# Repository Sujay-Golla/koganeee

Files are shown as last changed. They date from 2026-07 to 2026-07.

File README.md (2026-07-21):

# Koganeee 
(JJK Reference) Flying room voice assistant with a screen  

## Inspiration
As a Jujutsu Kaisen fan and an admirer of flying pets, I wanted to make Kogane for my room. The objective of Kogane is to be a person-following flying pet assistant that can communicate with voice and through a retractable screen, sort of like a flying Alexa but friendlier! I also wanted to make drones for a while and it seemed like a cool approach to make Kogane. A use case that I had in mind is when I'm working in my room and my hands are busy and if I need to quickly pull up a tutorial, I would normally have to put things down to find my laptop. Instead with Kogane, I can call for Kogane wherever I am in my room and quickly check for information or pull up a Youtube tutorial from its screen without any physical contact. 

## Challenges
I was new to building FCs and drones, so I had to spend a lot of time getting advice from my friends and revising designs. The timeline was also a bit tight as I had to finish it by Open Sauce

## Technical Features
In terms of the technical features, it is a drone controlled by a room-based camera-mmWave sensor fused navigation system. It has a mic and speaker for voice activation and vocal communication, as well as a retractable screen to present any information prompted by the user. It hosts 1303 Brushless motors, a big 1100mAH 4S LiPo battery, a custom FC with STM32F722RET6 and ESP32-S3-WROOM, an on-device camera for object detection, faceID, and AprilTag detection with potential for extension for radio control as needed. 

## CAD Model
### Kogane




### Internal Drone



## PCB
### Fabricated PCB



### Schematic





### PCB Design


### 3D Model



## BOM

| Item | Qty | Price (USD) | Link | Notes |
|---|-----|---|---|---|
| 1303 5500KV brushless motor | 4 | $67.61 | [Rotor Village](https://rotorvillage.ca/geprc-speedx2-1303-5-5500kv-motor/) | |
| 3-inch Gemfan 3018 2-Blade Propeller (4 pairs) | 1 | $3.94 | [AliExpress](https://www.aliexpress.com/item/1005007476443932.html) | |
| 4-in-1 ESC 45A 20x20 | 1 | $30.55 | [AliExpress](https://www.aliexpress.com/item/1005009278492069.html) | |
| GNB 1100mAh 4S 120C HV LiPo XT60 | 1 | $19.72 | [Rotor Village](https://rotorvillage.ca/gnb-1100mah-4s-120c-hv-lipo-xt60/) | |
| Battery strap | 1 | $3.88 | [AliExpress](https://www.aliexpress.com/item/4001316238579.html) | |
| Custom Kogane FC PCB | 1 | $168.84 | [JLCPCB](https://jlcpcb.com) | Design submitted |
| ESP32-S3-WROOM-1-N16R8 | 1 | $15.79 | [AliExpress](https://www.aliexpress.com/item/1005012502278371.html) | Manual solder |
| VL53L1X ToF sensor | 1 | $4.83 | [AliExpress](https://www.aliexpress.com/item/1005007324288727.html) | Manual solder |
| 8GB microSD card | 1 | $3.49 | [AliExpress](https://www.aliexpress.com/item/1005010323860143.html) | FAT32 for iNAV blackbox |
| OV2640 FPC camera module 75MM-160 650nm | 1 | $9.19 | [AliExpress](https://www.aliexpress.com/item/1005003040149873.html) | |
| ILI9341 2.8 inch SPI touch display | 1 | $5.69 | [AliExpress](https://www.aliexpress.com/item/1005006315533240.html) | |
| INMP441 I2S microphone | 1 | $1.59 | [AliExpress](https://www.aliexpress.com/item/1005009213592784.html) | |
| 4 ohm 3W speaker | 1 | $2.46 | [AliExpress](https://www.aliexpress.com/item/1005008626624201.html) | |
| MG90S micro servo | 0 | $0.00 | | Already owned |
| HLK-LD2450 mmWave module | 1 | $6.69 | [AliExpress](https://www.aliexpress.com/item/1005010228798692.html) | |
| USB-UART adapter 3.3V logic | 1 | $1.77 | [AliExpress](https://www.aliexpress.com/item/1005006445462581.html) | Powers LD2450 from laptop USB |
| USB webcam 720p or 1080p | 2 | $7.95 | [AliExpress](https://www.aliexpress.com/item/1005007740023631.html) | Fixed position to laptop USB |
| 4S LiPo charger with AC plug | 1 | $15.00 | [Amazon](https://www.amazon.ca/dp/B0B3Y3JGDG) | |
| XT60 Pigtail Male | 1 | $1.48 | [AliExpress](https://www.aliexpress.com/item/1005009156026988.html) | |
| Radio TX module | 1 | $4.23 | [AliExpress](https://www.aliexpress.com/item/1005010228737836.html) | For future integration as RC transmitter is currently out of budget |
| JST Connector kit | 1 | $6.09 | [AliExpress](https://www.aliexpress.com/item/1005010491522001.html) | |
| M2 nylon standoff kit | 1 | $3.68 | [AliExpress](https://www.aliexpress.com/item/32862529967.html) | |

**Total cost: $384.47**

## Credits
https://macondo.hackclub.com/docs/flight-controller#stm32cubemx - Very useful guide :D
Thanks to Surya and Alvik for all their guidance with the PCB and drone design!

## Note - Updated July 4
- Had to rush the firmware with Claude due to the timeline but tested different elements manually with test code and will continue working on it as I wait for the PCB and parts

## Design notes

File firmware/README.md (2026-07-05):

# KOGANE — Firmware Workflow (Baseline)

> Baseline firmware/software workflow for the whole Kogane system.
> This is a **skeleton + workflow**, not a finished flight stack. Each target builds
> and has clearly marked `TODO` stubs where real logic goes.
>
> Read `hardware/DESIGN.md` (architecture + pin map) and `hardware/WIRING_GUIDE.md` first.

---

## 1. System at a glance

Kogane is a companion drone. Perception/voice/fusion run **off-board on a laptop**;
the drone only stabilizes itself and follows position/velocity setpoints.

```
                 Wi-Fi UDP                         MAVLink (telem) + MSP (override)
 LD2450 nodes ───────────────►  LAPTOP (base)  ───────────────►  ESP32-S3  ───UART1───►  F722 (iNAV)
 (ESP32-C3 x2)                  fusion+voice+UI     Wi-Fi UDP     companion              flight core
                                       ▲                             │
 drone OV2640 ──MJPEG/Wi-Fi────────────┘                 I2S audio / SPI LCD / servo
```

There are **four firmware/software targets** in this repo:

| Dir | Target | Toolchain | What it does |
|-----|---|---|---|
| `fc-inav/` | STM32F722 flight core | iNAV 9.x (config, no C code) | rate/attitude stabilization, altitude hold (VL53L1X), DShot motors, RC+failsafe, blackbox |
| `companion-esp32s3/` | ESP32-S3-WROOM-1 | ESP-IDF | Wi-Fi/UDP link, FC bridge (MAVLink in / MSP override out), I2S audio, SPI display, OV2640 camera, servo |
| `mmwave-node-esp32c3/` | ESP32-C3 (x2) | ESP-IDF | read HLK-LD2450 over UART, forward targets as UDP to the laptop |
| `base-station/` | Laptop | Python 3.11+ | sensor fusion (Kalman), voice pipeline, setpoint sender, screen renderer |

Shared wire-protocol definitions live in [`shared/PROTOCOL.md`](shared/PROTOCOL.md).

The CubeMX file [`firmware.ioc`](firmware.ioc) is a **pinout reference only** — iNAV owns
clock/USB/peripheral config at runtime. Keep it in sync with `hardware/DESIGN.md §5`.

---

## 2. Protocols (who speaks what)

| Link | Transport | Protocol | Direction |
|---|---|---|---|
| LD2450 node → laptop | Wi-Fi UDP | `KGN` datagram (see PROTOCOL.md) | node → base |
| laptop → drone ESP32 | Wi-Fi UDP | `KGN` datagram (setpoints, screen, audio) | base ↔ drone |
| drone OV2640 → laptop | Wi-Fi (HTTP/MJPEG) | MJPEG stream | drone → base |
| ESP32-S3 → F722 (telem) | UART1 @ 115200 | **MAVLink v2** (iNAV telemetry out) | FC → ESP32 |
| ESP32-S3 → F722 (control) | UART1 (shared) | **MSP v2 override** | ESP32 → FC |

> **iNAV reality check:** iNAV emits MAVLink *telemetry* but does **not** ingest MAVLink
> position/velocity commands. Autonomous setpoints are injected with **MSP RC override**
> (`MSP_SET_RAW_RC` / MSP override). So the companion parses MAVLink for state and sends
> MSP frames for control on the same UART. See `companion-esp32s3/main/link_fc.*`.

---

## 3. Per-target build & flash

### 3.1 `fc-inav/` (iNAV on the F722)
No compiler needed for the baseline — you flash a stock iNAV build and apply a CLI diff.
```powershell
# 1. Flash iNAV via DFU: hold BOOT, tap RESET, then in iNAV Configurator flash the
#    matching F722 target (see fc-inav/README.md for target selection).
# 2. Open the CLI tab and paste the config:
#    fc-inav/config/kogane-fc.diff
```
To build a **custom target** from iNAV source, see `fc-inav/README.md`.

### 3.2 `companion-esp32s3/` and `mmwave-node-esp32c3/` (ESP-IDF)
```powershell
# one-time: install ESP-IDF v5.x and run export.ps1 in each new shell
idf.py set-target esp32s3      # (esp32c3 for the node)
idf.py menuconfig              # set Wi-Fi SSID/pass + Kogane options
idf.py build
idf.py -p COM<x> flash monitor
```

### 3.3 `base-station/` (Python on the laptop)
```powershell
cd base-station
python -m venv .venv; .\.venv\Scripts\Activate.ps1
pip install -e .
python -m kogane_base            # runs the orchestrator (all stubs wired together)
```

---

## 4. Recommended bring-up order

Mirrors `hardware/DESIGN.md §14`, but from the firmware side:

1. **FC alone** — flash iNAV, apply `kogane-fc.diff`, verify gyro (ICM-45686) + accel in Configurator.
2. **FC RC + motors (props off)** — bind ELRS on UART3, verify DShot order/direction, test failsafe.
3. **ESP32-S3 link** — flash companion, confirm it reads iNAV MAVLink telemetry over UART1.
4. **Base UDP loopback** — run `base-station`, confirm it exchanges `KGN` datagrams with the ESP32 over Wi-Fi.
5. **mmWave nodes** — flash ESP32-C3 nodes, confirm LD2450 targets arrive at the base as UDP.
6. **Fusion** — base produces a smooth (X, Y, heading) from mmWave (+ camera later).
7. **MSP override (motors off / tethered)** — base → ESP32 → MSP override moves the FC's virtual sticks.
8. **Payload** — camera stream, LCD, servo rollout, audio loopback.
9. **Tethered hover** with RC override ready, then enable the off-board position loop.

---

## 5. Repo layout
```
firmware/
├─ README.md                 # this file
├─ firmware.ioc              # CubeMX pinout reference (not built)
├─ shared/PROTOCOL.md        # wire formats (UDP + FC link)
├─ fc-inav/                  # iNAV target skeleton + CLI config
├─ companion-esp32s3/        # ESP-IDF companion firmware
├─ mmwave-node-esp32c3/      # ESP-IDF LD2450 bridge node
└─ base-station/             # Python base-station stack
```

## 6. Status / what is stubbed
Everything marked `TODO(kogane)` is a stub. The baseline goal is: **structure compiles,
tasks/threads exist, links are wired, and each block has one obvious place to add logic.**

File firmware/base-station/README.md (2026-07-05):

# KOGANE Base Station (laptop, Python)

The off-board brain. Fuses mmWave (+ camera) into a smooth target position, runs the voice
pipeline, streams UI to the drone screen, and sends velocity/position **setpoints** to the
drone over Wi-Fi UDP (which the ESP32 turns into MSP override for iNAV).

## Modules
| Module | File | Role |
|---|---|---|
| Net | `kogane_base/net/udp.py` | async UDP endpoint, `KGN` pack/unpack |
| Protocol | `kogane_base/protocol.py` | Python mirror of `shared/PROTOCOL.md` |
| mmWave | `kogane_base/tracking/mmwave.py` | ingest node datagrams -> raw detections |
| Fusion | `kogane_base/fusion/kalman.py` | constant-velocity Kalman -> (x, y, heading) |
| Setpoints | `kogane_base/link/setpoint.py` | position error -> velocity setpoint -> drone |
| Voice | `kogane_base/voice/pipeline.py` | wakeword -> STT -> LLM -> TTS (stubs) |
| Screen | `kogane_base/screen/renderer.py` | render UI frames, stream to drone display |
| Orchestrator | `kogane_base/main.py` | wires everything, runs the async loop |

## Run
```powershell
cd firmware/base-station
python -m venv .venv; .\.venv\Scripts\Activate.ps1
pip install -e .
python -m kogane_base        # starts UDP server + fusion + setpoint loop (voice/screen stubbed)
```

## Config
Edit `kogane_base/config.py` (or set env vars): UDP port, drone IP, room geometry, node corner
positions, follow distance, control gains. Corner placement of the two LD2450 nodes must match
`NODE_ID` in the node firmware so detections land in the right room frame.

## Status
Networking, protocol, mmWave ingest, a working Kalman filter, and a P-controller setpoint loop
are functional in skeleton form. Voice and screen are stubbed (`TODO(kogane)`), ready for
openWakeWord / Deepgram / Claude / ElevenLabs and the screen renderer.

---

## Computer vision (testable now, no drone needed)

`kogane_base/vision/` runs **person detection + tracking on the laptop webcam** — the fastest
way to validate the CV path before the drone camera exists.

```powershell
cd firmware/base-station
python -m venv .venv; .\.venv\Scripts\Activate.ps1
pip install -e .[vision]          # opencv-python + ultralytics (YOLOv8n auto-downloads)

kogane-cv                          # webcam, live window with boxes + tracked ids
python -m kogane_base.vision.demo --source webcam --fuse   # also run the Kalman filter
python -m kogane_base.vision.demo --source video  --path clip.mp4
python -m kogane_base.vision.demo --source mjpeg  --url http://<drone-ip>/stream
python -m kogane_base.vision.demo --headless       # no window, prints target position
```
Window keys: `q` quit, `l` lock/unlock onto the current primary target.

### What it does
| File | Role |
|---|---|
| `vision/sources.py` | webcam / video-file / MJPEG-stream frame sources (OpenCV) |
| `vision/detector.py` | YOLOv8n person detection + ByteTrack ids; `select_primary()` picks who to follow |
| `vision/geometry.py` | monocular bbox → bearing + rough distance → camera-frame (x, y) |
| `vision/demo.py` | the runnable test harness (draw, FPS, optional `--fuse`) |

### How it plugs into the rest later
`MonocularEstimator.estimate()` → `project_to_room()` produces a room-frame (x, y) in the
**same coordinate frame** as `tracking/mmwave.py`, so a camera detection is just another
`PositionFilter.update(x, y)` measurement. `--fuse` already demonstrates this on one target.

### Accuracy notes
- **Bearing** (left/right angle) is reliable. **Distance** is estimated from apparent person
  height (assumes ~1.7 m) — rough (±20–40%), fine for testing "closer = bigger" and the loop.
- For the **fixed room camera**, swap height-based distance for a floor-plane homography
  (4 clicked floor points) — marked `TODO(kogane)` in `geometry.py::project_to_room`.
- Set `--hfov` to your camera's real horizontal FOV for better numbers.

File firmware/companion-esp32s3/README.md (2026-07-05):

# KOGANE Companion — ESP32-S3-WROOM-1 (ESP-IDF)

On-board companion. Bridges the laptop (Wi-Fi UDP) to the F722 flight core, and drives
the drone payload (audio, display, camera, servo).

## Responsibilities
| Module | File | Role |
|---|---|---|
| Wi-Fi + UDP | `main/wifi_udp.*` | join Wi-Fi (STA), send/recv `KGN` datagrams to base |
| FC link | `main/link_fc.*` | parse iNAV **MAVLink** telemetry in; send **MSP** RC override out (UART1) |
| Audio | `main/audio_i2s.*` | INMP441 mic → base; base TTS → MAX98357A speaker (I2S) |
| Display | `main/display_spi.*` | ILI9341 + XPT2046 touch (SPI) |
| Camera | `main/camera_dvp.*` | OV2640 DVP → MJPEG HTTP stream |
| Servo | `main/servo_ledc.*` | MG90S screen rollout (LEDC PWM) |
| Messages | `main/kogane_msg.h` | `KGN` datagram structs (mirror of shared/PROTOCOL.md) |

## Build / flash
```powershell
idf.py set-target esp32s3
idf.py menuconfig      # Kogane -> Wi-Fi SSID/pass, base station IP/port, FC UART, pins
idf.py build
idf.py -p COM<x> flash monitor
```
Requires ESP-IDF v5.x. Camera needs the `esp32-camera` component (add via the IDF
component manager — see `main/idf_component.yml`).

## Pins (defaults; set final GPIOs in menuconfig — DESIGN.md §7)
FC UART1, I2S (mic + speaker), SPI (LCD+touch), DVP (OV2640), LEDC (servo). ESP32-S3
GPIO assignment is **not yet locked in hardware** — confirm before PCB route, then update
`Kconfig.projbuild` defaults.

## Status
All modules are FreeRTOS-task skeletons with `TODO(kogane)` stubs. `app_main` brings up
Wi-Fi, then starts each task. The control path (UDP setpoint → MSP override) and the
telemetry path (MAVLink → UDP DRONE_STATE) are wired end-to-end with placeholder logic.

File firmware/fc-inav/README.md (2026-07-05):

# KOGANE FC — iNAV 9.x

The flight core runs **stock iNAV 9.x**. We do not write flight C code; we (a) pick/build
a target for the custom STM32F722RET6 board and (b) apply a CLI config
([`config/kogane-fc.diff`](config/kogane-fc.diff)).

Pin map source of truth: `hardware/DESIGN.md §5`. CubeMX `firmware.ioc` is a reference only.

---

## Option A — quickest: use a stock F722 target (recommended for bring-up)

The custom board's pinout closely matches common F7 layouts. For first power-on:

1. Put the board in DFU: **hold BOOT, tap RESET** (see `hardware/WIRING_GUIDE.md §7`).
2. In **iNAV Configurator**, flash a generic **`MATEKF722`** (or nearest F722) target.
3. Go to **CLI**, paste `config/kogane-fc.diff`, then `save`.
4. Verify in the **Setup** tab: ICM-45686 detected, accel ~1 g flat, gyro quiet.

> Resource remaps in the diff repoint motors/UARTs/SPI/I2C to the Kogane pins. Any pin the
> stock target can't remap is called out in the diff comments — that's when you need Option B.

## Option B — custom unified target (for a clean board definition)

Build iNAV from source with the Kogane target in [`target/`](target/):

```bash
git clone https://github.com/iNavFlight/inav.git && cd inav
git checkout release_9.x                       # match the release you fly
cp -r <repo>/firmware/fc-inav/target/KOGANEF722 src/main/target/
make TARGET=KOGANEF722                          # or: docker build per iNAV BUILD.md
```
Flash the resulting `.hex` via DFU, then apply the CLI diff.

`target/KOGANEF722/` here is a **skeleton** — `target.h`/`target.c`/`config.c` list the
Kogane resources with `TODO(kogane)` markers to reconcile against the current iNAV target API
(the target macro set changes between iNAV majors; check `docs/development/` in the iNAV tree).

---

## Files
```
fc-inav/
├─ README.md
├─ config/kogane-fc.diff     # CLI diff: resources, features, ports, failsafe
└─ target/KOGANEF722/        # custom unified-target skeleton
   ├─ target.h
   ├─ target.c
   └─ config.c
```

## Key config decisions baked into the diff
- **Gyro:** ICM-45686 on SPI1 (`USE_IMU_ICM45686`). Bench-verify — driver is new in 9.x.
- **Motors:** DShot300 on TIM2 CH1–4 (PA0–PA3). **Verify DShot DMA** — see DESIGN.md §5 note.
- **RC:** CRSF (ELRS) on UART3.
- **ESP32/MSP + MAVLink telemetry:** UART1. MSP override enabled for off-board setpoints.
- **Altitude:** VL53L1X rangefinder on I2C1.
- **Blackbox:** SDMMC (microSD).
- **Battery:** VBAT ADC on the divider; set `vbat_scale` after calibrating.

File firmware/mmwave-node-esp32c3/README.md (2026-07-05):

# KOGANE mmWave Node — ESP32-C3 (ESP-IDF)

One per HLK-LD2450. Reads the radar's tracked targets over UART and forwards them to the
laptop as `KGN` `MMWAVE_TARGETS` UDP datagrams. Deploy **2 nodes** in opposite room corners.

## Data path
```
LD2450  ──UART 256000──►  ESP32-C3  ──Wi-Fi UDP (KGN)──►  laptop (kogane_base)
```

## Build / flash
```powershell
idf.py set-target esp32c3
idf.py menuconfig     # Kogane Node -> Wi-Fi, base IP/port, node id, LD2450 UART pins
idf.py build
idf.py -p COM<x> flash monitor
```

## LD2450 frame format (implemented in `main/ld2450.c`)
Report frames: header `AA FF 03 00`, 3 targets × 8 bytes (x, y, speed, resolution),
footer `55 CC`. Coordinates are signed (sign bit in the high bit, mm units). See the
HLK-LD2450 serial protocol datasheet. `NODE_ID` (menuconfig) tags each node's datagrams
so the base can place them by corner.

## Status
`ld2450.c` parses frames from a byte stream; `wifi_udp.c` joins Wi-Fi and sends datagrams.
The `main.c` loop wires read → parse → send with `TODO(kogane)` markers for the decode math.

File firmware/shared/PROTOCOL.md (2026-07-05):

# KOGANE — Wire Protocols (shared)

Single source of truth for the message formats used across the base station, the
drone companion (ESP32-S3), and the mmWave nodes (ESP32-C3). Keep the C header
(`companion-esp32s3/main/kogane_msg.h`) and the Python module
(`base-station/kogane_base/protocol.py`) in sync with this file.

---

## 1. `KGN` UDP datagram (Wi-Fi)

All Wi-Fi UDP traffic uses one framed datagram. Little-endian. Default port **`5005`**.

```
offset  size  field        notes
0       3     magic        ASCII "KGN"
3       1     version      = 1
4       1     msg_type     see table below
5       1     flags        bit0 = ack_requested
6       2     seq          u16 rolling sequence
8       4     src_id       device id (e.g. node index, drone=0)
12      2     len          payload length
14      len   payload      msg_type-specific (below)
14+len  2     crc16        CCITT over bytes [0 .. 14+len)
```

### msg_type values
| id | name | dir | payload |
|----|---|-----|---|
| 0x01 | `MMWAVE_TARGETS` | node → base | `mmwave_targets` |
| 0x10 | `SETPOINT` | base → drone | `setpoint` |
| 0x11 | `MODE_CMD` | base → drone | `mode_cmd` |
| 0x20 | `DRONE_STATE` | drone → base | `drone_state` |
| 0x30 | `SCREEN_FRAME` | base → drone | `screen_frame` (chunked) |
| 0x40 | `AUDIO_TTS` | base → drone | PCM/opus chunk |
| 0x41 | `AUDIO_MIC` | drone → base | PCM/opus chunk |
| 0x7F | `HEARTBEAT` | any | `heartbeat` |

### payload structs
```
mmwave_targets:   u8 count; then count × { i16 x_mm; i16 y_mm; i16 speed_cms; u16 res_mm }
setpoint:         i16 vx_cms; i16 vy_cms; i16 vz_cms; i16 yaw_rate_cds; u8 ctrl_mode
                  (ctrl_mode: 0=hold, 1=velocity, 2=position)
mode_cmd:         u8 mode  (0=idle,1=arm,2=takeoff,3=follow,4=land,5=dock,6=failsafe)
drone_state:      i16 x_cm; i16 y_cm; i16 z_cm; i16 yaw_cd; u16 batt_mv; u8 flags; u8 link_q
heartbeat:        u32 uptime_ms; u8 role   (0=base,1=drone,2=node)
```

`crc16` = CRC-16/CCITT-FALSE (poly 0x1021, init 0xFFFF).

---

## 2. FC link (ESP32-S3 ↔ F722, UART1 @ 115200)

Two protocols share this UART:

- **MAVLink v2 (inbound telemetry):** iNAV is configured with a MAVLink telemetry
  port. The companion parses `HEARTBEAT`, `ATTITUDE`, `SYS_STATUS`, `GPS_RAW_INT`/
  `LOCAL_POSITION_NED` (as available) to build `DRONE_STATE`.
- **MSP v2 (outbound control):** setpoints become **MSP RC override** frames
  (`MSP_SET_RAW_RC`, or iNAV MSP override) mapping vx/vy/vz/yaw → RC channels.
  iNAV does **not** accept MAVLink setpoints, hence MSP here.

> Mapping `setpoint` → RC channels is defined in `companion-esp32s3/main/link_fc.c`.
> Keep channel order aligned with the `map`/`rc` settings in `fc-inav/config/kogane-fc.diff`.

---

## 3. Camera stream (OV2640 → laptop)

Independent of `KGN`: the companion serves **MJPEG over HTTP** (`http://<drone-ip>/stream`).
The base pulls frames for Face-ID / obstacle CV. Not on the UDP control path so it never
blocks setpoints.

---

## 4. Versioning

Bump `version` in the datagram header and this doc together. Base station rejects
mismatched versions with a logged warning.

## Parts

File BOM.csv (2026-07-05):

Item Name | Qty | Price (total USD) | Item Link | Notes
1303 5500KV brushless motor | 4 | $67.61 | https://rotorvillage.ca/geprc-speedx2-1303-5-5500kv-motor/
3-inch Gemfan 3018 2-Blade Propeller (4 pairs) | 1 | $3.94 | https://www.aliexpress.com/item/1005007476443932.html
4-in-1 ESC 45A 20x20 | 1 | $30.55 | https://www.aliexpress.com/item/1005009278492069.html
GNB 1100mAh 4S 120C HV LiPo XT60 | 1 | $19.72 | https://rotorvillage.ca/gnb-1100mah-4s-120c-hv-lipo-xt60/
Battery strap | 1 | $3.88 | https://www.aliexpress.com/item/4001316238579.html
Custom Kogane FC PCB | 1 | $168.84 | https://jlcpcb.com | Design submitted
ESP32-S3-WROOM-1-N16R8 | 1 | $15.79 | https://www.aliexpress.com/item/1005012502278371.html | Manual solder
VL53L1X ToF sensor | 1 | $4.83 | https://www.aliexpress.com/item/1005007324288727.html | Manual solder
8GB microSD card | 1 | $3.49 | https://www.aliexpress.com/item/1005010323860143.html | FAT32 for iNAV blackbox
OV2640 FPC camera module 75MM-160 650nm | 1 | $9.19 | https://www.aliexpress.com/item/1005003040149873.html
ILI9341 2.8 inch SPI touch display | 1 | $5.69 | https://www.aliexpress.com/item/1005006315533240.html
INMP441 I2S microphone | 1 | $1.59 | https://www.aliexpress.com/item/1005009213592784.html
4 ohm 3W speaker | 1 | $2.46 | https://www.aliexpress.com/item/1005008626624201.html
MG90S micro servo | 0 | $0.00 |  | Already owned
HLK-LD2450 mmWave module | 1 | $6.69 | https://www.aliexpress.com/item/1005010228798692.html
USB-UART adapter 3.3V logic | 1 | $1.77 | https://www.aliexpress.com/item/1005006445462581.html | Powers LD2450 from laptop USB
USB webcam 720p or 1080p | 2 | $7.95 | https://www.aliexpress.com/item/1005007740023631.html | Fixed position to laptop USB
4S LiPo charger with AC plug | 1 | $15.00 | https://www.amazon.ca/dp/B0B3Y3JGDG
XT60 Pigtail Male | 1 | $1.48 | https://www.aliexpress.com/item/1005009156026988.html
Radio TX module | 1 | $4.23 | https://www.aliexpress.com/item/1005010228737836.html | For future integration as RC transmitter is currently out of budget
JST Connector kit | 1 | $6.09 | https://www.aliexpress.com/item/1005010491522001.html
M2 nylon standoff kit | 1 | $3.68 | https://www.aliexpress.com/item/32862529967.html

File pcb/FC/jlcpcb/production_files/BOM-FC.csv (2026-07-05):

Comment | Designator | Footprint | LCSC | Quantity
100k | R7 | R0603 | C2933198 | 1
100k | R11,R20,R8 | R0402 | C844504 | 3
100n | C1,C10,C12,C13,C14,C15,C16,C25,C26,C6,C9 | C0603 | C1591 | 11
100u | C34 | C1210 | C162511 | 1
10k | R12,R13,R14,R15,R16,R17,R22,R3,R6 | R0603 | C2933198 | 9
10u | C20 | C0603 | C1591 | 1
13.7k | R10 | R0603 | C2933198 | 1
1u | C17,C18,C19,C29,C30,C31,C32,C33,C8 | C0603 | C1591 | 9
2.2u | C11,C2,C5 | C0603 | C1591 | 3
20p | C23,C24 | C0603 | C1591 | 2
22.1k | R9 | R0402 | C844504 | 1
22u | C28,C3,C35,C7 | C0805 | C602037 | 4
3.6k | R4,R5 | R0603 | C2933198 | 2
330 | R19,R21 | R0603 | C2933198 | 2
4.7u | C27 | C0603 | C1591 | 1
5.1k | R1,R18,R2 | R0603 | C2933198 | 3
5.6u | L1 | IND-SMD_L7.0-W6.6_APH0630 | C5349708 | 1
6.8p | C21,C22 | C0603 | C1591 | 2
6.8u | L2 | IND-SMD_L7.1-W6.6 | C5349706 | 1
BSMD2920L-1000-16V | F1 | F2920 | C46597958 | 1
CAMERA | FPC1 | FPC-SMD_0510-GX-24PWB-GF-RB | C52722656 | 1
DMG3415U | Q1,Q2 | SOT-23-3_L2.9-W1.3-P1.90-LS2.4-BR-1 | C7202986 | 2
FCM1608KF-601T03 | L3 | L0603 | C141723 | 1
ICM-45686 | U2 | LGA-14_L3.0-W2.5-P0.50-TL | C22459454 | 1
LED | D3,D5 | LED0603-FD | C19171390 | 2
LMR51430XDDCR | U6,U7 | SOT-23-6_L2.9-W1.6-P0.95-LS2.8-BL | C5185863 | 2
Q13FC1350000400 | X2 | FC-135R_L3.2-W1.5 | C32346 | 1
RB088LAM-40TR | D1,D2 | SOD-128_L3.7-W2.5-LS4.7-RD | C3758383 | 2
SDCard-TF-01A | Card1 | TF-SMD_TF-01A | C91145 | 1
SMAJ18A_C148219 | D4 | SMA_L4.4-W2.6-LS5.0-RD | C148219 | 1
TS-1088-AR02016 | SW1,SW2,SW3 | SW-SMD_L3.9-W3.0-P4.45 | C720477 | 3
USB TYPE-C 16PIN 2MD | USB1 | USB-C-SMD_TYPE-C-16PIN-2MD-073 | C2765186 | 1
X322525MOB4SI | X1 | CRYSTAL-SMD_4P-L3.2-W2.5-BL | C9006 | 1
XC6206-1.2V_C49446790 | U10 | SOT-23-3_L3.0-W1.6-P1.90-LS2.8-BR | C49446790 | 1
XC6206-2.8V | U8 | SOT-23-3_L2.9-W1.6-P1.90-LS2.8-BR | C2892669 | 1
XC6206P332MR | U9 | SOT-23-3_L2.9-W1.6-P1.90-LS2.8-BR | C5446 | 1
RC | J7 | JST_XH_B4B-XH-A_1x04_P2.50mm_Vertical |  | 1
MIC_2 | J3 | JST_XH_B3B-XH-A_1x03_P2.50mm_Vertical |  | 1
MIC_1 | J2 | JST_XH_B3B-XH-A_1x03_P2.50mm_Vertical |  | 1
MAX98357A | U11 | TQFN-16-1EP_3x3mm_P0.5mm_EP1.23x1.23mm |  | 1
FC-ESC | J1 | JST_XH_B8B-XH-AM_1x08_P2.50mm_Vertical |  | 1
ESP32-S3-WROOM-1 | U4 | ESP32-S3-WROOM-1 |  | 1
VL53L1CXV0FY1 | U5 | ST_VL53L1x |  | 1
STM32F722RETx | U1 | LQFP-64_10x10mm_P0.5mm |  | 1
SCREEN | J4 | JST_XH_B14B-XH-A_1x14_P2.50mm_Vertical |  | 1
SERVO | J5 | JST_XH_B3B-XH-A_1x03_P2.50mm_Vertical |  | 1
SPEAKER | J6 | JST_XH_B2B-XH-A_1x02_P2.50mm_Vertical |  | 1

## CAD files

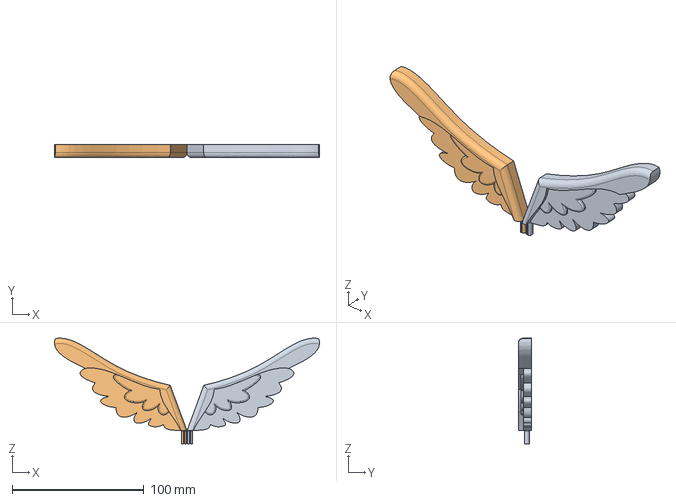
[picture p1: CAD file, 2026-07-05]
cad/Wings.step
201.4 x 10.0 x 80.3 mm

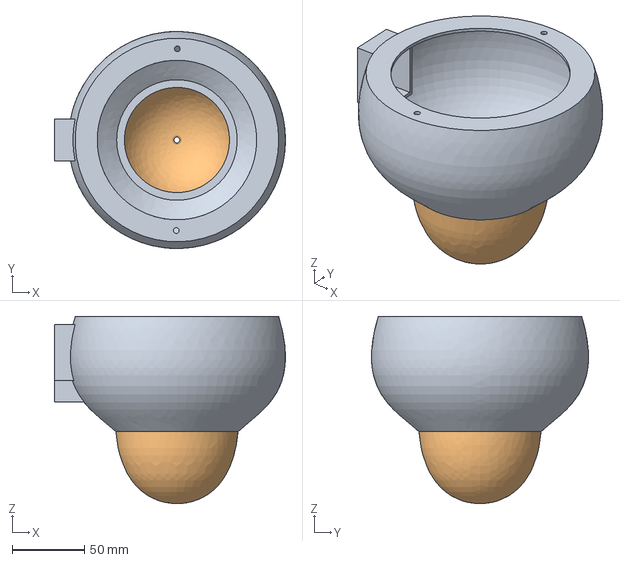
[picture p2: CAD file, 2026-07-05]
cad/Body.step
160.4 x 150.6 x 129.9 mm

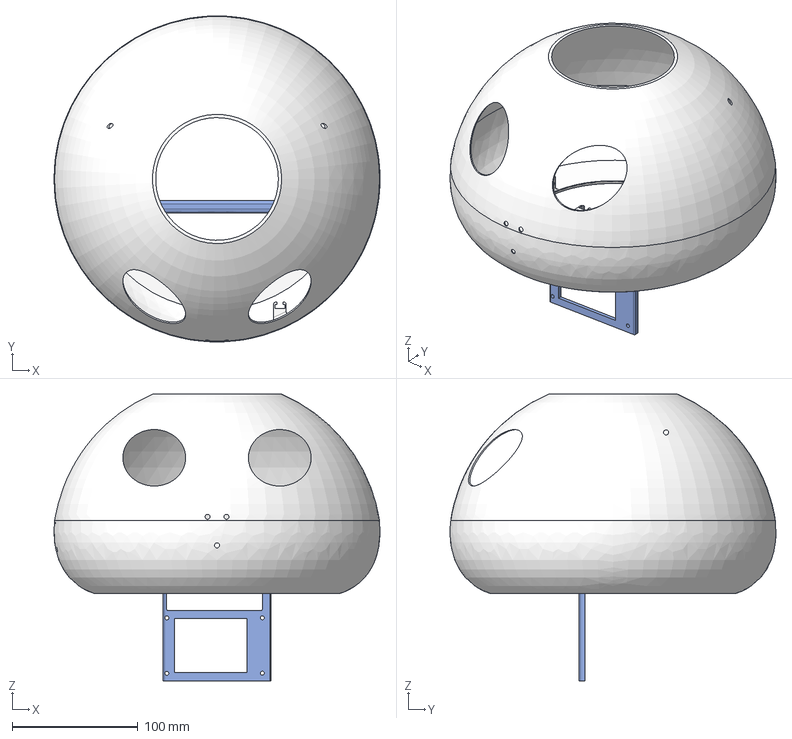
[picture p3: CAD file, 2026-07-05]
cad/Head v3.step
259.7 x 259.6 x 228.4 mm

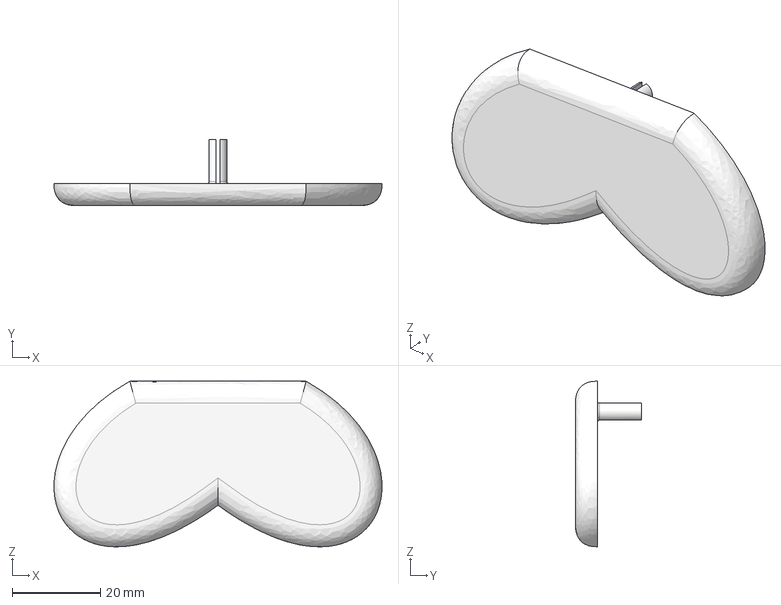
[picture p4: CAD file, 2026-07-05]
cad/Nose.step
74.4 x 15.0 x 37.6 mm

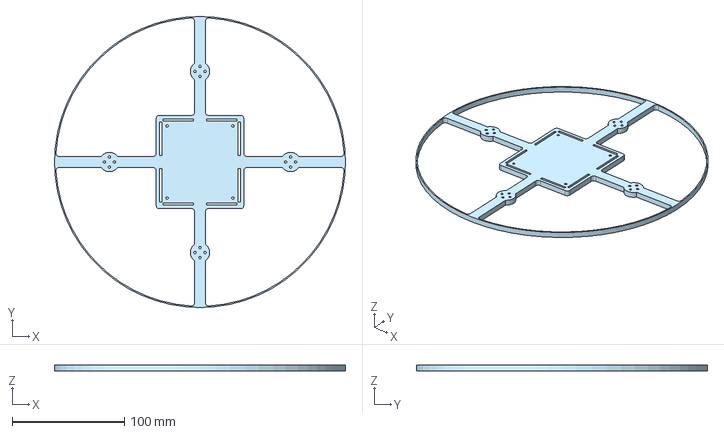
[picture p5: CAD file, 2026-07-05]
cad/Drone body.step
259.2 x 259.2 x 5.00 mm

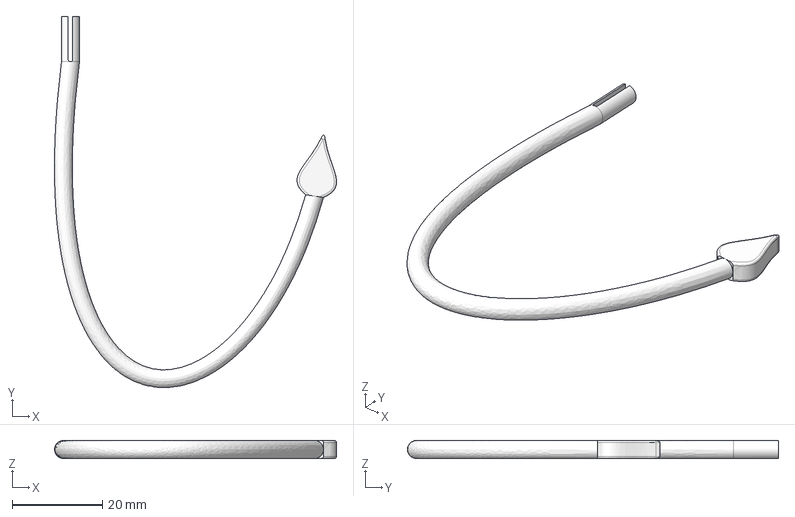
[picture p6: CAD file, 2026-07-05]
cad/Tail.step
62.4 x 82.1 x 4.00 mm

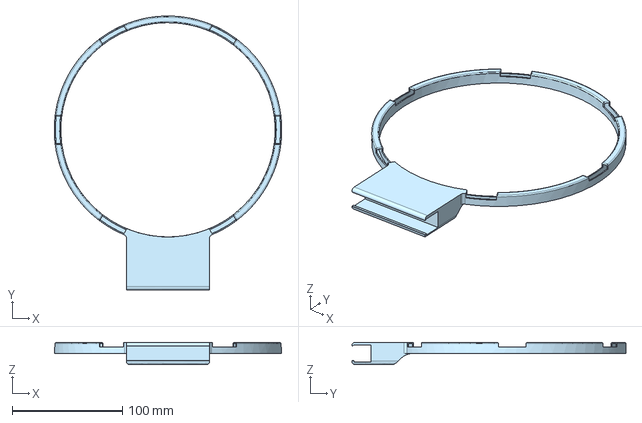
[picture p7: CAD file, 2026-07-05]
cad/Ground station.step
205.9 x 248.0 x 20.0 mm

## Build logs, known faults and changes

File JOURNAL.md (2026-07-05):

# Journal for building Kogane
Total number of hours: 59

## May 31 - Working on BOM
### Hours spent: 2

Spent some time figuring out how to deal with the placement of different components and the scope of this project. Firstly, I decided that it made sense to use lightweight models for voice and video, keeping it limited so that it can run independently on A7S rather than relying on my laptop. Then I decided to have 2 mmWave sensors to cover blindspots and detect position of humans in the room, and decided it would be cool to integrate CV with mmWave, so added a fixed camera to help inform the drone position. A small FPV camera on the drone can allow it to avoid obstacles, and it would be cool to integrate VISTA (a research paper about drones navigating unknown maps) at least for initial calibration. Still figuring out the feasibility of a custom FC or if it would be easier to have a basic FC and a separate ESP32 for communication, camera and for extending the project to control servos for the rolling screen and a gripper in the future. Drafted the BOM but will find more stuff on AliExpress tomorrow.

## June 8 - Working on the sketch
### Hours spent: 3

I wanted to pitch my project as an X-tier project for Stardance, so I started making a sketch to explain my idea to Alex. I had to change a few things to make my life easier and to make the project more feasible. Firstly, I changed the scope so that rather than having a rollable screen with multiple screens, I would just have one large screen with the lower body of kogane being lowered using strings and servos. Then, I went to explore the different modules I would need to make my custom FC, including the STM32, an IMU, ESCs and ESP32 with its peripherals like OV2640, INMP441, MAX98357A, 4ohm speaker, etc. Also decided to use the LiPo 3S battery and to create the ground station, first I explored the possibility of magnetic docking with pogo pins but then realized it would be difficult and complicated. So rather it will be a manual charging connection for now. I decided to use USB Webcams connected with long wires to simplify the compute and directly connect to the A7S without compromising latency. Will also have a mmWave sensor near the ground station for detection in the dark. One concern is still that the CV aspect will be a bit difficult since it is my first time doing it and it might be safer to resort to IR cameras and use IR reflectors on the drone to detect position precisely, but that is an aspect of the scope I can change as I shop for the materials. My next immediate goal is to finish the FC and CAD.


## Note: The rest was done through Lapse/Lookout and logged with the Stardance project

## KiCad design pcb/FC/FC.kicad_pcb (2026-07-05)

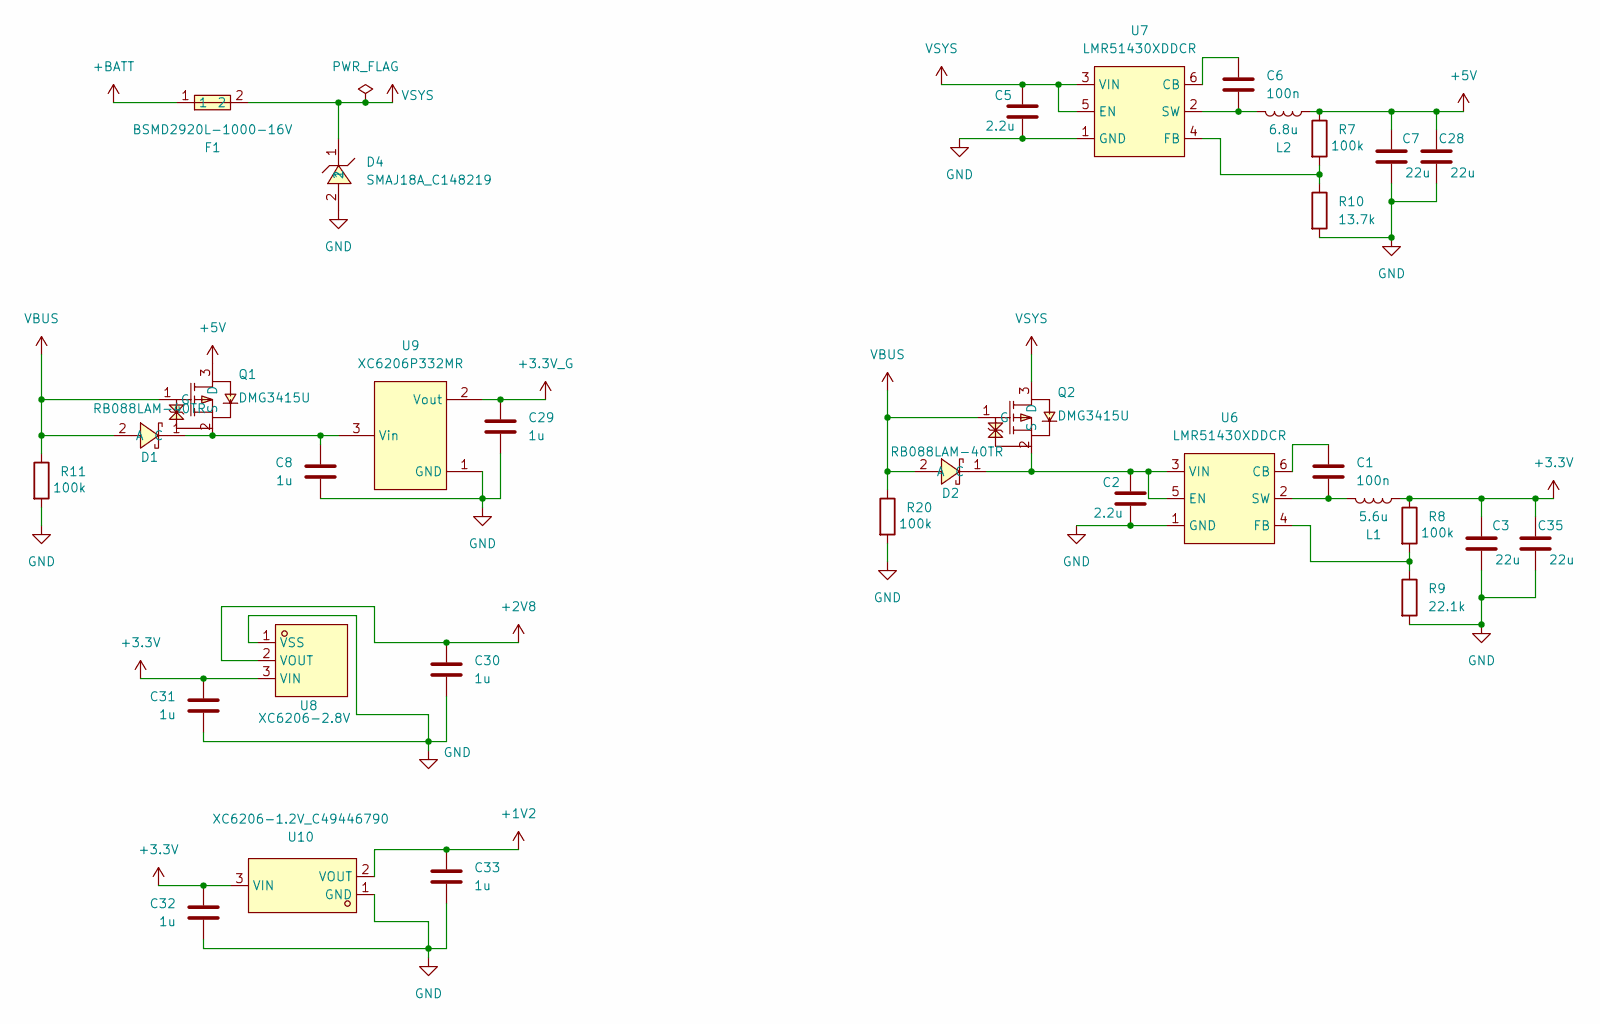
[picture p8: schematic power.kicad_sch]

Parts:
C1, C6: 100n; C0603
C2, C5: 2.2u; C0603
C3, C7, C28, C35: 22u; C0805
C8, C29, C30, C31, C32, C33: 1u; C0603
D1, D2: RB088LAM-40TR; SOD-128_L3.7-W2.5-LS4.7-RD; MPN RB088LAM-40TR; LCSC Part C3758383
D4: SMAJ18A_C148219; SMA_L4.4-W2.6-LS5.0-RD; MPN SMAJ18A; LCSC Part C148219
F1: BSMD2920L-1000-16V; F2920; MPN BSMD2920L-1000-16V; LCSC Part C46597958
L1: 5.6u; IND-SMD_L7.0-W6.6_APH0630
L2: 6.8u; IND-SMD_L7.1-W6.6
Q1, Q2: DMG3415U; SOT-23-3_L2.9-W1.3-P1.90-LS2.4-BR-1; MPN DMG3415U; LCSC Part C7202986
R7: 100k; R0603
R8, R11, R20: 100k; R0402
R9: 22.1k; R0402
R10: 13.7k; R0603
U6, U7: LMR51430XDDCR; SOT-23-6_L2.9-W1.6-P0.95-LS2.8-BL; MPN LMR51430XDDCR; LCSC Part C5185863
U8: XC6206-2.8V; SOT-23-3_L2.9-W1.6-P1.90-LS2.8-BR; MPN XC6206-2.8V; LCSC Part C2892669
U9: XC6206P332MR; SOT-23-3_L2.9-W1.6-P1.90-LS2.8-BR; MPN XC6206P332MR-G; LCSC Part C5446
U10: XC6206-1.2V_C49446790; SOT-23-3_L3.0-W1.6-P1.90-LS2.8-BR; MPN XC6206-1.2V; LCSC Part C49446790

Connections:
+1V2: C33.1, U10.2 (VOUT); also elsewhere on the board
+2V8: C30.1, U8.2 (VOUT); also elsewhere on the board
+3.3V: C3.1, C31.1, C32.1, C35.1, L1.2, R8.1, U8.3 (VIN), U10.3 (VIN); also elsewhere on the board
+3.3V_G: C29.1, U9.2 (Vout); also elsewhere on the board
+5V: C7.1, C28.1, L2.2, Q1.3 (D), R7.1; also elsewhere on the board
+BATT: F1.1; also elsewhere on the board
GND: C2.2, C3.2, C5.2, C7.2, C8.2, C28.2, C29.2, C30.2, C31.2, C32.2, C33.2, C35.2, D4.2, R9.2, R10.2, R11.2, R20.2, U6.1 (GND), U7.1 (GND), U8.1 (VSS), U9.1 (GND), U10.1 (GND); also elsewhere on the board
unnamed: C8.1, D1.1 (C), Q1.2 (S), U9.3 (Vin)
unnamed: C2.1, D2.1 (C), Q2.2 (S), U6.3 (VIN), U6.5 (EN)
unnamed: C1.1, U6.6 (CB)
unnamed: R8.2, R9.1, U6.4 (FB)
unnamed: C1.2, L1.1, U6.2 (SW)
unnamed: C6.1, U7.6 (CB)
unnamed: R7.2, R10.1, U7.4 (FB)
unnamed: C6.2, L2.1, U7.2 (SW)
VBUS: D1.2 (A), D2.2 (A), Q1.1 (G), Q2.1 (G), R11.1, R20.1; also elsewhere on the board
VSYS: C5.1, D4.1, F1.2, Q2.3 (D), U7.3 (VIN), U7.5 (EN)

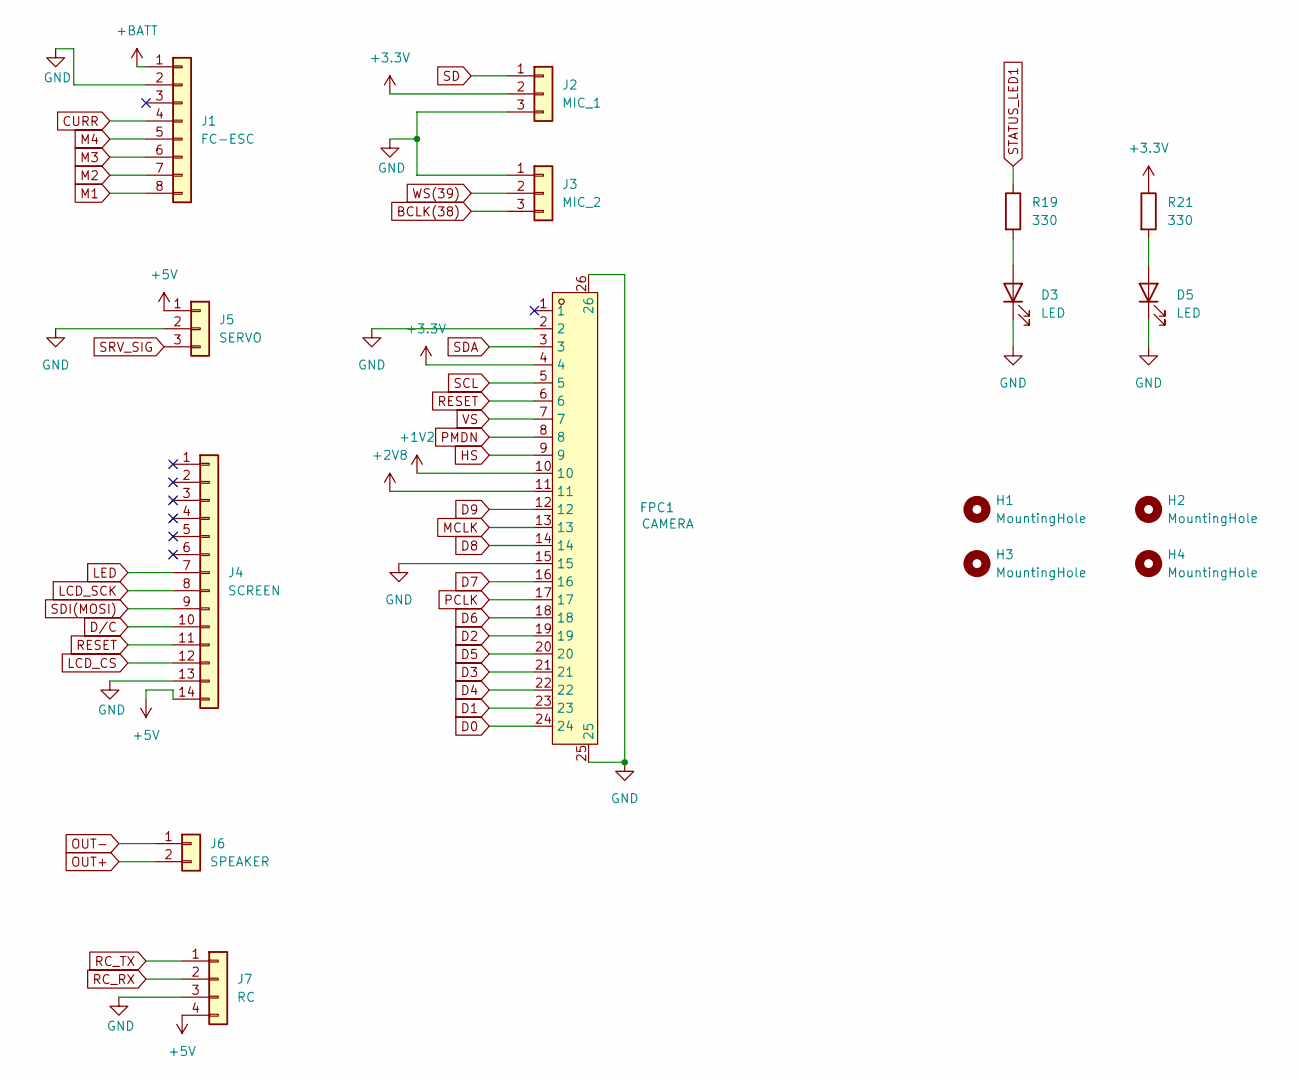
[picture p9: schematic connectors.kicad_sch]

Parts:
D3, D5: LED; LED0603-FD
FPC1: CAMERA; FPC-SMD_0510-GX-24PWB-GF-RB; MPN 0510-GX-24PWB-GF-RB; LCSC Part C52722656
H1, H2, H3, H4: MountingHole; MountingHole_2.2mm_M2_Pad_Via
J1: FC-ESC; JST_XH_B8B-XH-AM_1x08_P2.50mm_Vertical
J2: MIC_1; JST_XH_B3B-XH-A_1x03_P2.50mm_Vertical
J3: MIC_2; JST_XH_B3B-XH-A_1x03_P2.50mm_Vertical
J4: SCREEN; JST_XH_B14B-XH-A_1x14_P2.50mm_Vertical
J5: SERVO; JST_XH_B3B-XH-A_1x03_P2.50mm_Vertical
J6: SPEAKER; JST_XH_B2B-XH-A_1x02_P2.50mm_Vertical
J7: RC; JST_XH_B4B-XH-A_1x04_P2.50mm_Vertical
R19, R21: 330; R0603

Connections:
+1V2: FPC1.10; also elsewhere on the board
+2V8: FPC1.11; also elsewhere on the board
+3.3V: FPC1.4, J2.2, R21.1; also elsewhere on the board
+5V: J4.14, J5.1, J7.4; also elsewhere on the board
+BATT: J1.1; also elsewhere on the board
BCLK(38): J3.3; also elsewhere on the board
CURR: J1.4; also elsewhere on the board
D0: FPC1.24; also elsewhere on the board
D1: FPC1.23; also elsewhere on the board
D2: FPC1.19; also elsewhere on the board
D3: FPC1.21; also elsewhere on the board
D4: FPC1.22; also elsewhere on the board
D5: FPC1.20; also elsewhere on the board
D6: FPC1.18; also elsewhere on the board
D7: FPC1.16; also elsewhere on the board
D8: FPC1.14; also elsewhere on the board
D9: FPC1.12; also elsewhere on the board
D/C: J4.10; also elsewhere on the board
GND: D3.1 (K), D5.1 (K), FPC1.2, FPC1.15, FPC1.25, FPC1.26, J1.2, J2.3, J3.1, J4.13, J5.2, J7.3; also elsewhere on the board
HS: FPC1.9; also elsewhere on the board
LCD_CS: J4.12; also elsewhere on the board
LCD_SCK: J4.8; also elsewhere on the board
LED: J4.7; also elsewhere on the board
M1: J1.8; also elsewhere on the board
M2: J1.7; also elsewhere on the board
M3: J1.6; also elsewhere on the board
M4: J1.5; also elsewhere on the board
MCLK: FPC1.13; also elsewhere on the board
unnamed: D3.2 (A), R19.2
unnamed: D5.2 (A), R21.2
OUT+: J6.2; also elsewhere on the board
OUT-: J6.1; also elsewhere on the board
PCLK: FPC1.17; also elsewhere on the board
PMDN: FPC1.8; also elsewhere on the board
RC_RX: J7.2; also elsewhere on the board
RC_TX: J7.1; also elsewhere on the board
RESET: FPC1.6, J4.11; also elsewhere on the board
SCL: FPC1.5; also elsewhere on the board
SD: J2.1; also elsewhere on the board
SDA: FPC1.3; also elsewhere on the board
SDI(MOSI): J4.9; also elsewhere on the board
SRV_SIG: J5.3; also elsewhere on the board
STATUS_LED1: R19.1; also elsewhere on the board
VS: FPC1.7; also elsewhere on the board
WS(39): J3.2; also elsewhere on the board

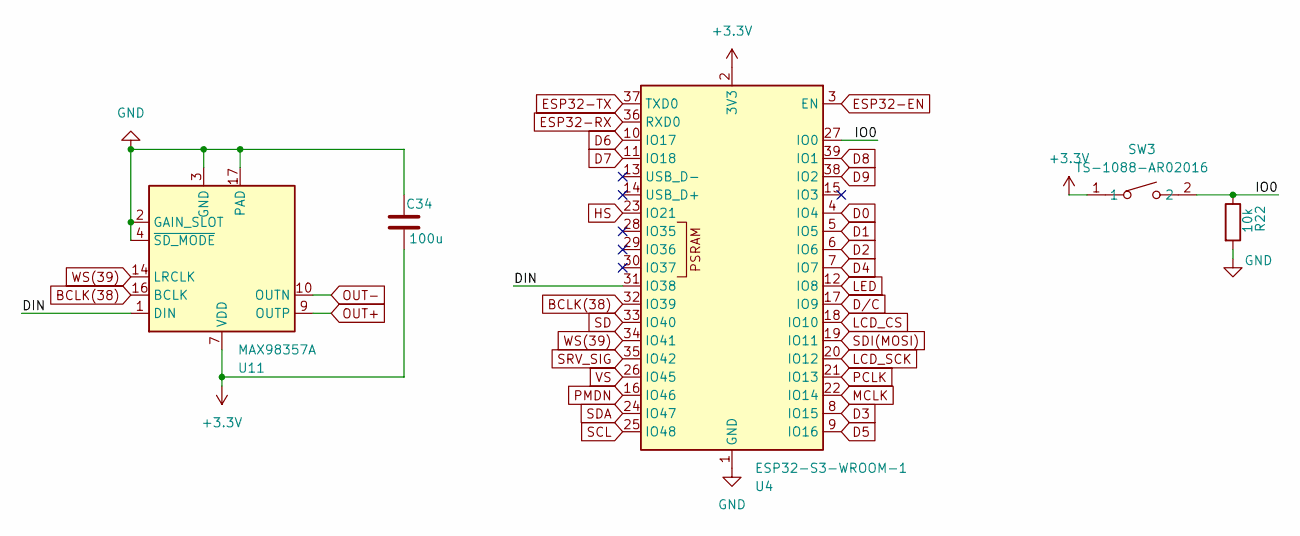
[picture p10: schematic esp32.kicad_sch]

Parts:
C34: 100u; C1210
R22: 10k; R0603
SW3: TS-1088-AR02016; SW-SMD_L3.9-W3.0-P4.45; MPN TS-1088-AR02016; LCSC Part C720477
U4: ESP32-S3-WROOM-1
U11: MAX98357A; TQFN-16-1EP_3x3mm_P0.5mm_EP1.23x1.23mm

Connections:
+3.3V: C34.2, SW3.1, U4.2 (3V3), U11.7 (VDD), U11.8 (VDD); also elsewhere on the board
/ESP32/DIN: U4.31 (IO38), U11.1 (DIN)
/ESP32/IO0: R22.1, SW3.2, U4.27 (IO0)
BCLK(38): U4.32 (IO39), U11.16 (BCLK); also elsewhere on the board
D0: U4.4 (IO4); also elsewhere on the board
D1: U4.5 (IO5); also elsewhere on the board
D2: U4.6 (IO6); also elsewhere on the board
D3: U4.8 (IO15); also elsewhere on the board
D4: U4.7 (IO7); also elsewhere on the board
D5: U4.9 (IO16); also elsewhere on the board
D6: U4.10 (IO17); also elsewhere on the board
D7: U4.11 (IO18); also elsewhere on the board
D8: U4.39 (IO1); also elsewhere on the board
D9: U4.38 (IO2); also elsewhere on the board
D/C: U4.17 (IO9); also elsewhere on the board
ESP32-EN: U4.3 (EN); also elsewhere on the board
ESP32-RX: U4.36 (RXD0); also elsewhere on the board
ESP32-TX: U4.37 (TXD0); also elsewhere on the board
GND: C34.1, R22.2, U4.1 (GND), U4.40 (GND), U4.41 (GND), U11.2 (GAIN_SLOT), U11.3 (GND), U11.4 (~SD_MODE), U11.11 (GND), U11.15 (GND), U11.17 (PAD); also elsewhere on the board
HS: U4.23 (IO21); also elsewhere on the board
LCD_CS: U4.18 (IO10); also elsewhere on the board
LCD_SCK: U4.20 (IO12); also elsewhere on the board
LED: U4.12 (IO8); also elsewhere on the board
MCLK: U4.22 (IO14); also elsewhere on the board
OUT+: U11.9 (OUTP); also elsewhere on the board
OUT-: U11.10 (OUTN); also elsewhere on the board
PCLK: U4.21 (IO13); also elsewhere on the board
PMDN: U4.16 (IO46); also elsewhere on the board
SCL: U4.25 (IO48); also elsewhere on the board
SD: U4.33 (IO40); also elsewhere on the board
SDA: U4.24 (IO47); also elsewhere on the board
SDI(MOSI): U4.19 (IO11); also elsewhere on the board
SRV_SIG: U4.35 (IO42); also elsewhere on the board
VS: U4.26 (IO45); also elsewhere on the board
WS(39): U4.34 (IO41), U11.14 (LRCLK); also elsewhere on the board

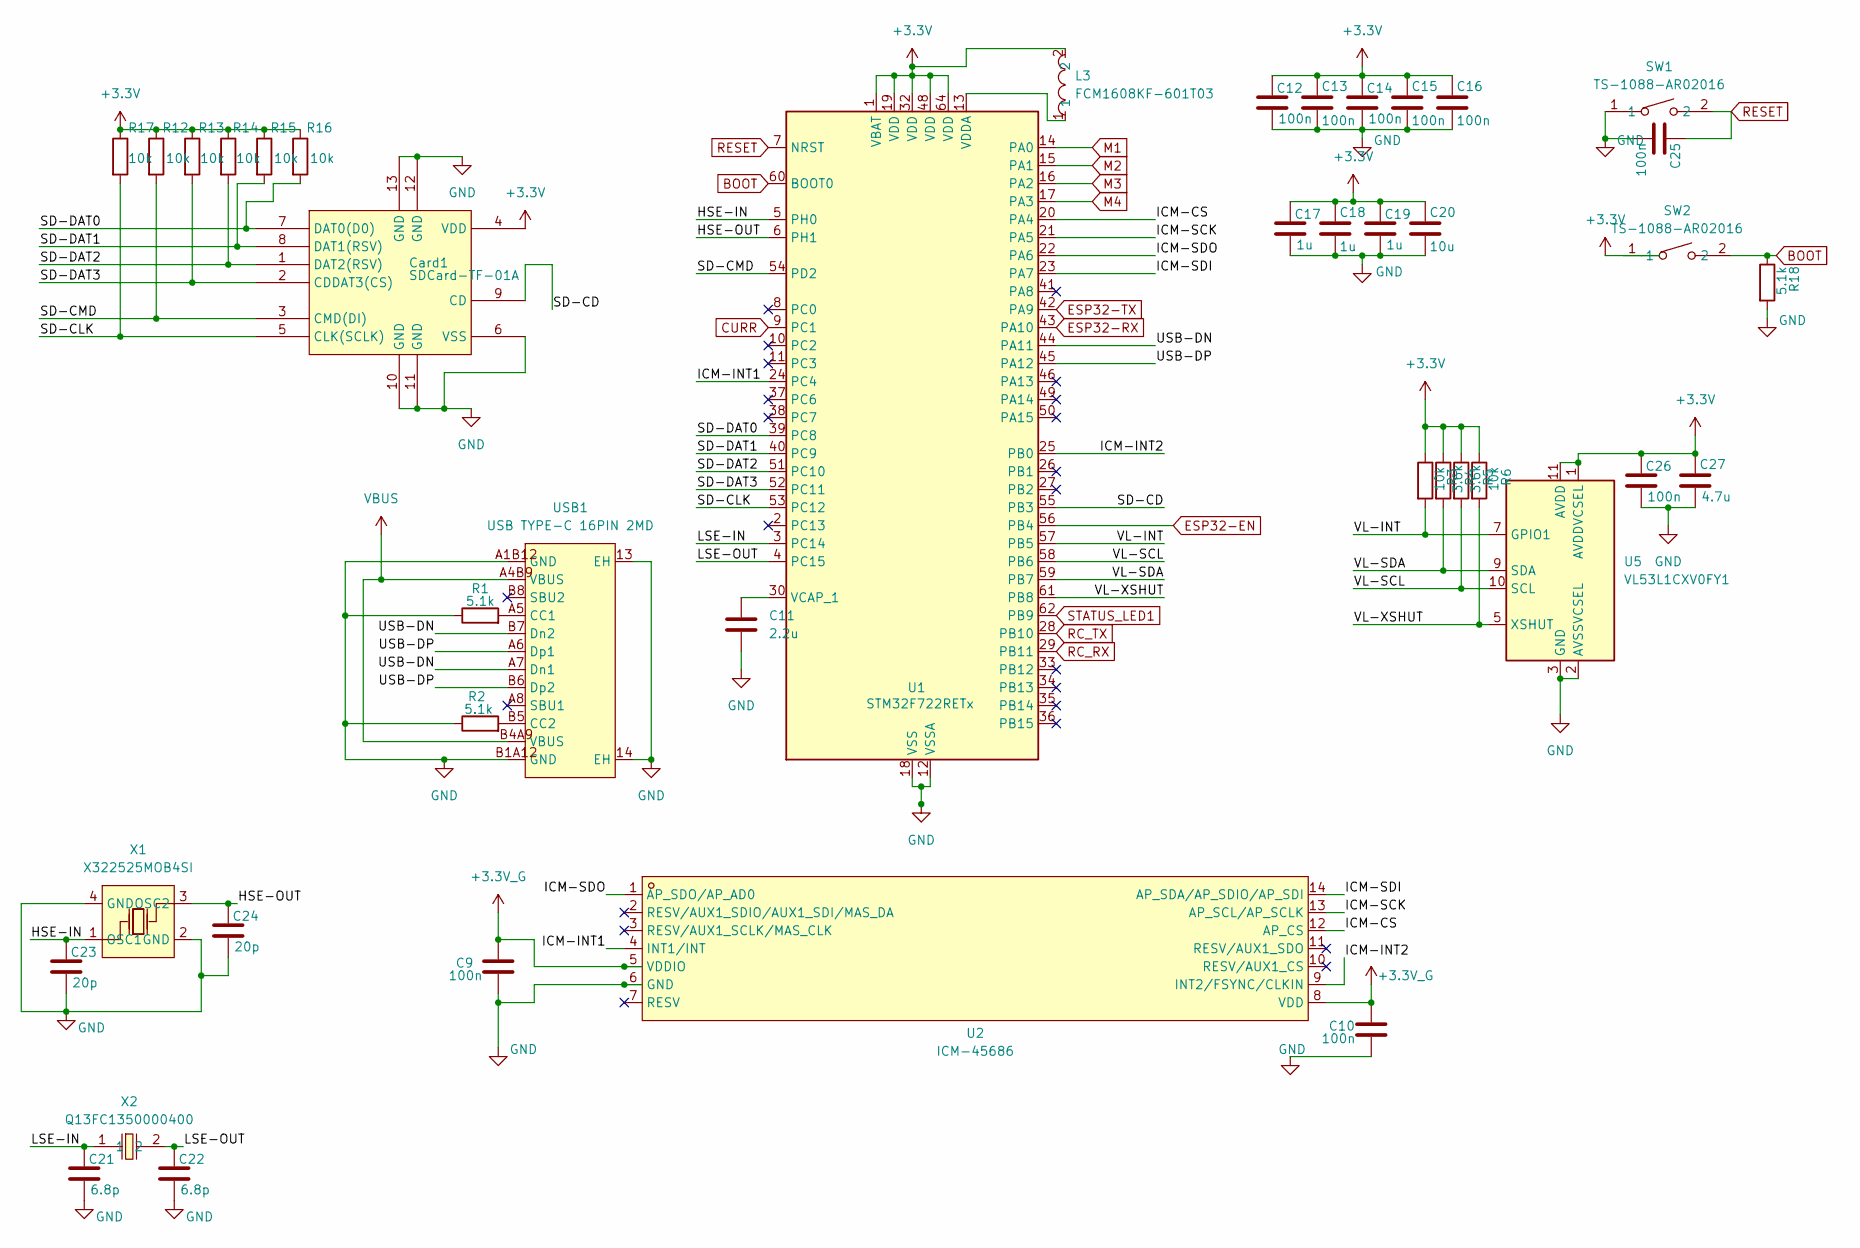
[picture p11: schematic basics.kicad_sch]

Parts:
C9, C10, C12, C13, C14, C15, C16, C25, C26: 100n; C0603
C11: 2.2u; C0603
C17, C18, C19: 1u; C0603
C20: 10u; C0603
C21, C22: 6.8p; C0603
C23, C24: 20p; C0603
C27: 4.7u; C0603
Card1: SDCard-TF-01A; TF-SMD_TF-01A; MPN TF-01A; LCSC Part C91145
L3: FCM1608KF-601T03; L0603; MPN FCM1608KF-601T03; LCSC Part C141723
R1, R2, R18: 5.1k; R0603
R3, R6, R12, R13, R14, R15, R16, R17: 10k; R0603
R4, R5: 3.6k; R0603
SW1, SW2: TS-1088-AR02016; SW-SMD_L3.9-W3.0-P4.45; MPN TS-1088-AR02016; LCSC Part C720477
U1: STM32F722RETx; LQFP-64_10x10mm_P0.5mm
U2: ICM-45686; LGA-14_L3.0-W2.5-P0.50-TL; MPN ICM-45686; LCSC Part C22459454
U5: VL53L1CXV0FY1; ST_VL53L1x
USB1: USB TYPE-C 16PIN 2MD; USB-C-SMD_TYPE-C-16PIN-2MD-073; MPN TYPE-C 16PIN 2MD(073); LCSC Part C2765186
X1: X322525MOB4SI; CRYSTAL-SMD_4P-L3.2-W2.5-BL; MPN X322525MOB4SI; LCSC Part C9006
X2: Q13FC1350000400; FC-135R_L3.2-W1.5; MPN Q13FC13500004; LCSC Part C32346

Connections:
+3.3V: C12.1, C13.1, C14.1, C15.1, C16.1, C17.1, C18.1, C19.1, C20.1, C26.1, C27.1, Card1.4 (VDD), L3.2, R3.1, R4.1, R5.1, R6.1, R12.1, R13.1, R14.1, R15.1, R16.1, R17.1, SW2.1, U1.1 (VBAT), U1.19 (VDD), U1.32 (VDD), U1.48 (VDD), U1.64 (VDD), U5.1 (AVDDVCSEL), U5.11 (AVDD); also elsewhere on the board
+3.3V_G: C9.1, C10.1, U2.5 (VDDIO), U2.8 (VDD); also elsewhere on the board
/Basics/HSE-IN: C23.1, U1.5 (PH0), X1.1 (OSC1)
/Basics/HSE-OUT: C24.1, U1.6 (PH1), X1.3 (OSC2)
/Basics/ICM-CS: U1.20 (PA4), U2.12 (AP_CS)
/Basics/ICM-INT1: U1.24 (PC4), U2.4 (INT1/INT)
/Basics/ICM-INT2: U1.25 (PB0), U2.9 (INT2/FSYNC/CLKIN)
/Basics/ICM-SCK: U1.21 (PA5), U2.13 (AP_SCL/AP_SCLK)
/Basics/ICM-SDI: U1.23 (PA7), U2.14 (AP_SDA/AP_SDIO/AP_SDI)
/Basics/ICM-SDO: U1.22 (PA6), U2.1 (AP_SDO/AP_AD0)
/Basics/LSE-IN: C21.1, U1.3 (PC14), X2.1
/Basics/LSE-OUT: C22.1, U1.4 (PC15), X2.2
/Basics/SD-CD: Card1.9 (CD), U1.55 (PB3)
/Basics/SD-CLK: Card1.5 (CLK(SCLK)), R17.2, U1.53 (PC12)
/Basics/SD-CMD: Card1.3 (CMD(DI)), R12.2, U1.54 (PD2)
/Basics/SD-DAT0: Card1.7 (DAT0(D0)), R16.2, U1.39 (PC8)
/Basics/SD-DAT1: Card1.8 (DAT1(RSV)), R15.2, U1.40 (PC9)
/Basics/SD-DAT2: Card1.1 (DAT2(RSV)), R14.2, U1.51 (PC10)
/Basics/SD-DAT3: Card1.2 (CDDAT3(CS)), R13.2, U1.52 (PC11)
/Basics/USB-DN: U1.44 (PA11), USB1.A7 (Dn1), USB1.B7 (Dn2)
/Basics/USB-DP: U1.45 (PA12), USB1.A6 (Dp1), USB1.B6 (Dp2)
/Basics/VL-INT: R3.2, U1.57 (PB5), U5.7 (GPIO1)
/Basics/VL-SCL: R5.2, U1.58 (PB6), U5.10 (SCL)
/Basics/VL-SDA: R4.2, U1.59 (PB7), U5.9 (SDA)
/Basics/VL-XSHUT: R6.2, U1.61 (PB8), U5.5 (XSHUT)
BOOT: R18.1, SW2.2, U1.60 (BOOT0)
CURR: U1.9 (PC1); also elsewhere on the board
ESP32-EN: U1.56 (PB4); also elsewhere on the board
ESP32-RX: U1.43 (PA10); also elsewhere on the board
ESP32-TX: U1.42 (PA9); also elsewhere on the board
GND: C9.2, C10.2, C11.2, C12.2, C13.2, C14.2, C15.2, C16.2, C17.2, C18.2, C19.2, C20.2, C21.2, C22.2, C23.2, C24.2, C25.2, C26.2, C27.2, Card1.6 (VSS), Card1.10 (GND), Card1.11 (GND), Card1.12 (GND), Card1.13 (GND), R1.1, R2.1, R18.2, SW1.1, U1.12 (VSSA), U1.18 (VSS), U1.31 (VSS), U1.47 (VSS), U1.63 (VSS), U2.6 (GND), U5.2 (AVSSVCSEL), U5.3 (GND), U5.4 (GND), U5.6 (GND), U5.12 (GND), USB1.13 (EH), USB1.14 (EH), USB1.A1B12 (GND), USB1.B1A12 (GND), X1.2 (GND), X1.4 (GND); also elsewhere on the board
M1: U1.14 (PA0); also elsewhere on the board
M2: U1.15 (PA1); also elsewhere on the board
M3: U1.16 (PA2); also elsewhere on the board
M4: U1.17 (PA3); also elsewhere on the board
unnamed: C11.1, U1.30 (VCAP_1)
unnamed: L3.1, U1.13 (VDDA)
unnamed: R1.2, USB1.A5 (CC1)
unnamed: R2.2, USB1.B5 (CC2)
RC_RX: U1.29 (PB11); also elsewhere on the board
RC_TX: U1.28 (PB10); also elsewhere on the board
RESET: C25.1, SW1.2, U1.7 (NRST); also elsewhere on the board
STATUS_LED1: U1.62 (PB9); also elsewhere on the board
VBUS: USB1.A4B9 (VBUS), USB1.B4A9 (VBUS); also elsewhere on the board

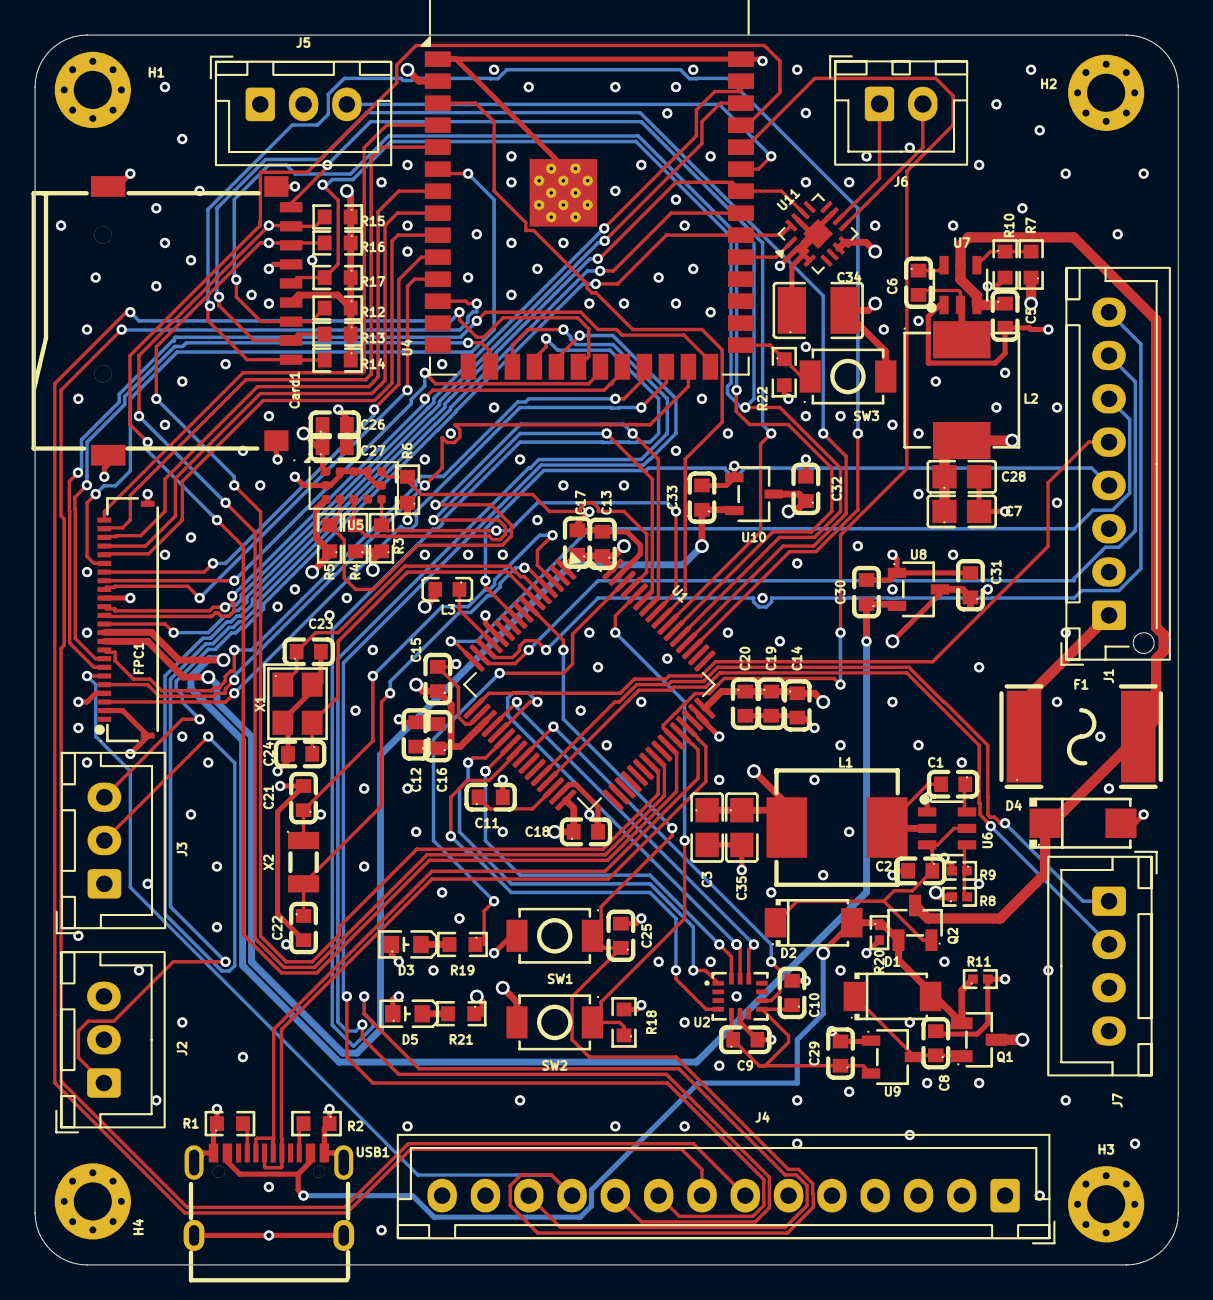
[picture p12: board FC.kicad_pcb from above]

Board: 4 copper layers, 66.0 x 71.0 mm, 96 parts (0 on the bottom side), 89 nets.

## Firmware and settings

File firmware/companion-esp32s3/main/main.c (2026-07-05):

/*
 * KOGANE companion (ESP32-S3) — app entry.
 * Brings up Wi-Fi, then starts the payload + link tasks. Each task lives in its
 * own module and is a skeleton; see the corresponding .c file.
 */
#include <string.h>
#include "freertos/FreeRTOS.h"
#include "freertos/task.h"
#include "nvs_flash.h"
#include "esp_log.h"

#include "wifi_udp.h"
#include "link_fc.h"
#include "audio_i2s.h"
#include "display_spi.h"
#include "camera_dvp.h"
#include "servo_ledc.h"

static const char *TAG = "kogane";

void app_main(void)
{
    ESP_LOGI(TAG, "Kogane companion boot");

    esp_err_t err = nvs_flash_init();
    if (err == ESP_ERR_NVS_NO_FREE_PAGES || err == ESP_ERR_NVS_NEW_VERSION_FOUND) {
        ESP_ERROR_CHECK(nvs_flash_erase());
        ESP_ERROR_CHECK(nvs_flash_init());
    }

    // Networking first: the control + telemetry loops depend on UDP being up.
    wifi_udp_start();

    // FC bridge: MAVLink telemetry in, MSP override out (UART1).
    link_fc_start();

    // Payload subsystems (safe to start even if hardware not attached — they stub out).
    servo_ledc_start();
    audio_i2s_start();
    display_spi_start();
    camera_dvp_start();

    ESP_LOGI(TAG, "all subsystems started");
    // app_main returns; FreeRTOS keeps the created tasks running.
}

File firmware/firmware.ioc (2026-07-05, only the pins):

Mcu.UserName=STM32F722RETx
PA0-WKUP.Signal=S_TIM2_CH1_ETR
PA1.Signal=S_TIM2_CH2
PA10.GPIO_Label=ESP32-RX
PA10.Signal=USART1_RX
PA11.Signal=USB_OTG_FS_DM
PA12.Signal=USB_OTG_FS_DP
PA2.Signal=S_TIM2_CH3
PA3.Signal=S_TIM2_CH4
PA4.GPIO_Label=ICM-CS
PA4.Signal=SPI1_NSS
PA5.GPIO_Label=ICM-SCK
PA5.Signal=SPI1_SCK
PA6.GPIO_Label=ICM-SDO
PA6.Signal=SPI1_MISO
PA7.GPIO_Label=ICM-SDI
PA7.Signal=SPI1_MOSI
PA9.GPIO_Label=ESP32-TX
PA9.Signal=USART1_TX
PB0.GPIO_Label=ICM-INT2
PB0.Signal=GPXTI0
PB10.Signal=USART3_TX
PB11.Signal=USART3_RX
PB3.GPIO_Label=SD-CD
PB3.Signal=GPIO_Input
PB4.GPIO_Label=ESP32-EN
PB4.Signal=GPIO_Output
PB5.GPIO_Label=VL-INT
PB5.Signal=GPXTI5
PB6.GPIO_Label=VL-SCL
PB6.Signal=I2C1_SCL
PB7.GPIO_Label=VL-SDA
PB7.Signal=I2C1_SDA
PB8.GPIO_Label=VL-XSHUT
PB8.Signal=GPIO_Output
PB9.GPIO_Label=STATUS_LED1
PB9.Signal=GPIO_Output
PC1.Signal=ADCx_IN11
PC10.Signal=SDMMC1_D2
PC11.Signal=SDMMC1_D3
PC12.Signal=SDMMC1_CK
PC14-OSC32_IN.Signal=RCC_OSC32_IN
PC15-OSC32_OUT.Signal=RCC_OSC32_OUT
PC8.Signal=SDMMC1_D0
PC9.Signal=SDMMC1_D1
PD2.Signal=SDMMC1_CMD
PH0-OSC_IN.Signal=RCC_OSC_IN
PH1-OSC_OUT.Signal=RCC_OSC_OUT

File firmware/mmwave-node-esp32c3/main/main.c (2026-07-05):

/*
 * KOGANE mmWave node (ESP32-C3): LD2450 UART -> parse -> KGN UDP to base.
 */
#include <string.h>
#include "freertos/FreeRTOS.h"
#include "freertos/task.h"
#include "driver/uart.h"
#include "nvs_flash.h"
#include "esp_log.h"

#include "ld2450.h"
#include "wifi_udp.h"

static const char *TAG = "node";
#define LD_UART  (CONFIG_KGN_LD2450_UART_NUM)

/* --- KGN framing (mirror of shared/PROTOCOL.md; send-only subset) --- */
static uint16_t crc16(const uint8_t *d, size_t n)
{
    uint16_t crc = 0xFFFF;
    for (size_t i = 0; i < n; ++i) {
        crc ^= (uint16_t)d[i] << 8;
        for (int b = 0; b < 8; ++b) crc = (crc & 0x8000) ? (crc << 1) ^ 0x1021 : (crc << 1);
    }
    return crc;
}

static uint16_t s_seq = 0;

static void send_targets(const ld2450_report_t *r)
{
    uint8_t frame[64];
    // header (14 bytes)
    frame[0]='K'; frame[1]='G'; frame[2]='N'; frame[3]=1; frame[4]=0x01; frame[5]=0;
    frame[6]=s_seq & 0xFF; frame[7]=s_seq >> 8; s_seq++;
    uint32_t src = CONFIG_KGN_NODE_ID;
    memcpy(&frame[8], &src, 4);
    // payload: u8 count + count * 8 bytes
    uint8_t *p = &frame[14];
    uint8_t count = 0, *pcount = p++; // reserve count byte
    for (int i = 0; i < LD2450_MAX_TARGETS; ++i) {
        if (!r->targets[i].valid) continue;
        int16_t x = r->targets[i].x_mm, y = r->targets[i].y_mm, v = r->targets[i].speed_cms;
        uint16_t res = r->targets[i].res_mm;
        memcpy(p, &x, 2); memcpy(p+2, &y, 2); memcpy(p+4, &v, 2); memcpy(p+6, &res, 2);
        p += 8; count++;
    }
    *pcount = count;
    uint16_t plen = 1 + count * 8;
    frame[12] = plen & 0xFF; frame[13] = plen >> 8;
    uint16_t crc = crc16(frame, 14 + plen);
    memcpy(&frame[14 + plen], &crc, 2);
    wifi_udp_send(frame, 14 + plen + 2);
}

static void node_task(void *arg)
{
    uint8_t rx[128];
    ld2450_report_t report;
    while (1) {
        int n = uart_read_bytes(LD_UART, rx, sizeof(rx), pdMS_TO_TICKS(50));
        if (n > 0 && ld2450_feed(rx, n, &report)) {
            send_targets(&report);
        }
    }
}

void app_main(void)
{
    esp_err_t err = nvs_flash_init();
    if (err == ESP_ERR_NVS_NO_FREE_PAGES || err == ESP_ERR_NVS_NEW_VERSION_FOUND) {
        ESP_ERROR_CHECK(nvs_flash_erase());
        ESP_ERROR_CHECK(nvs_flash_init());
    }
    wifi_udp_start();

    uart_config_t uc = {
        .baud_rate = 256000, .data_bits = UART_DATA_8_BITS,
        .parity = UART_PARITY_DISABLE, .stop_bits = UART_STOP_BITS_1,
        .flow_ctrl = UART_HW_FLOWCTRL_DISABLE, .source_clk = UART_SCLK_DEFAULT,
    };
    ESP_ERROR_CHECK(uart_driver_install(LD_UART, 1024, 0, 0, NULL, 0));
    ESP_ERROR_CHECK(uart_param_config(LD_UART, &uc));
    ESP_ERROR_CHECK(uart_set_pin(LD_UART, CONFIG_KGN_LD2450_TX, CONFIG_KGN_LD2450_RX,
                                 UART_PIN_NO_CHANGE, UART_PIN_NO_CHANGE));
    xTaskCreate(node_task, "ld2450", 4096, NULL, 6, NULL);
    ESP_LOGI(TAG, "node %d up", CONFIG_KGN_NODE_ID);
}

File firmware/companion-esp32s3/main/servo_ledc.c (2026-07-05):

/*
 * MG90S screen-rollout servo (LEDC 50 Hz PWM). Presets: SCREEN_HIDDEN / SCREEN_VISIBLE.
 * This one is functional enough to move a servo; tune min/max pulse to your mechanism.
 */
#include "driver/ledc.h"
#include "esp_log.h"
#include "servo_ledc.h"

static const char *TAG = "servo_ledc";

#define SERVO_TIMER     LEDC_TIMER_0
#define SERVO_MODE      LEDC_LOW_SPEED_MODE
#define SERVO_CHANNEL   LEDC_CHANNEL_0
#define SERVO_RES       LEDC_TIMER_14_BIT   // 16384 counts
#define SERVO_FREQ_HZ   50                  // 20 ms period
#define SERVO_MIN_US    500                 // ~0 deg  (tune)
#define SERVO_MAX_US    2400                // ~180 deg (tune)

static uint32_t us_to_duty(int us)
{
    // duty = counts * (pulse_us / period_us); period = 20000us at 50Hz
    return (uint32_t)(((uint64_t)us * ((1 << 14) - 1)) / 20000);
}

void servo_set_deg(int deg)
{
    if (deg < 0) deg = 0; if (deg > 180) deg = 180;
    int us = SERVO_MIN_US + (SERVO_MAX_US - SERVO_MIN_US) * deg / 180;
    ledc_set_duty(SERVO_MODE, SERVO_CHANNEL, us_to_duty(us));
    ledc_update_duty(SERVO_MODE, SERVO_CHANNEL);
}

void servo_ledc_start(void)
{
    ledc_timer_config_t t = {
        .speed_mode = SERVO_MODE, .timer_num = SERVO_TIMER,
        .duty_resolution = SERVO_RES, .freq_hz = SERVO_FREQ_HZ, .clk_cfg = LEDC_AUTO_CLK,
    };
    ledc_timer_config(&t);
    ledc_channel_config_t c = {
        .gpio_num = CONFIG_KGN_SERVO_GPIO, .speed_mode = SERVO_MODE,
        .channel = SERVO_CHANNEL, .timer_sel = SERVO_TIMER,
        .duty = 0, .hpoint = 0,
    };
    ledc_channel_config(&c);
    servo_set_deg(0);   // SCREEN_HIDDEN at boot
    ESP_LOGI(TAG, "servo ready on GPIO%d", CONFIG_KGN_SERVO_GPIO);
}

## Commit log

2026-06-01 starting BOM and Journal
    [BOM.csv]
2026-06-13 Update BOM.csv with new items and pricing in CAD
    [BOM.csv]
2026-07-05 Finishing the design and preparing for submission
    [BOM-FC.csv, BOM.csv, Body.step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]
2026-07-05 Update README with CAD, PCB, and 3D model images
    Added images and sections for CAD model, internal drone, PCB schematic, PCB design, and 3D model.
2026-07-05 Revise Radio TX module description in BOM
    Updated the note for the Radio TX module to reflect future integration plans.
    [BOM.csv]
2026-07-21 Add images for fabricated PCB in README
2026-09-25 Add companion bring-up, base station features, and PCB updates
    Document the verified hardware state and wire protocol, add companion display/audio/camera/telemetry drivers, expand the Python base station and tests, and capture PCB source/manufacturing changes. S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
2026-10-19 Add staged firmware bring-up and integrated demo tools
    Add validated FC telemetry and bounded UART checks, LCD and microphone bring-up, voice tasks and live weather, and radar/camera mapping tools. Include the custom UART3 firmware image and operating gu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
2026-10-19 Document current firmware setup and PCB revision fixes
2026-10-19 Enhance README with project details and images
    Updated README with additional details on challenges, technical features, and next steps. Added images and clarified PCB design status.
2026-10-19 Revise README with clearer issue descriptions
    Updated the README to clarify fixes for the ESP32 boot and other issues, improving descriptions and adding details for better understanding.
2026-10-19 Label servo connection as PWM
2026-10-20 Enhance details in JOURNAL.md entries
    Updated various entries in JOURNAL.md to provide more detailed descriptions of tasks and experiences related to ESP32, soldering, and debugging.
2026-10-20 Revise parts list and update total cost
    Updated the quantity and total cost in the parts list, added a new item, and revised notes for the custom PCB.
2026-10-20 Modify BOM.csv with new quantities and items
    Updated quantities and added optional items in BOM.
2026-10-20 Update Radiomaster Pocket URL in BOM.csv
    Removed unnecessary query parameters from the Radiomaster Pocket URL.
2026-11-04 Update BOM.csv
    Added filament
2026-11-04 Add KiCanvas badge for PCB design
    Added a badge to view PCB design on KiCanvas.
2026-11-04 Modify PCB link in README
    Updated PCB link to point to the FC directory.
